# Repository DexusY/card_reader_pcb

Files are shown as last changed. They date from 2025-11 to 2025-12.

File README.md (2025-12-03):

# ESP32 RFID Access Control System

A compact and robust access control system based on the **ESP32-WROOM-32E** microcontroller and the **RFID-RC522** reader. This project allows for controlling an electric strike, electromagnetic lock, or gate upon presenting an authorized card.

The system is designed to run on **12V DC**, making it easy to integrate with standard alarm and intercom systems.

---

## PCB Visualization

The PCB design (2-layer) prioritizes power stability and RF signal integrity.

### Key PCB Features:
* **RF Optimization:** Dedicated "Keep-out zone" under the ESP32 antenna to ensure maximum WiFi/Bluetooth range.
* **Stable Power Delivery:** Wide power rails for the 3.3V line to prevent voltage drops during high current peaks.
* **Safety:** Physical isolation slots routed near the relay to increase creepage distance and safety.

PCB Traces view
PCB 3D View

---

## Schematic & Functional Description

The system is divided into three main functional blocks.

### 1. Power Supply Section
The input stage accepts **12V DC**. It utilizes a modern **LMR51610** (SOT-23-6) step-down converter to efficiently lower the voltage to the **3.3V** required by the ESP32 and RFID module.
* **Input:** 12V DC (Screw Terminal J1).
* **Filtering:** Ceramic capacitors and a 1.5uH inductor ensure a stable output.

Power Supply Schematic

### 2. MCU & User Interface
The core of the system is the **ESP32-WROOM-32E**. It handles the logic, wireless communication, and user feedback:
* **Feedback:** A Buzzer (BZ1) and 3 LEDs (Red, Yellow, Green) indicate access status.
* **Programming:** Exposed UART header (J3) with TX, RX, GND, 3.3V, IO0 (BOOT), and EN pins.

MCU Schematic
Goldpins connectors for programing and module

### 3. Actuator Output
The lock control mechanism is driven by a relay via an NPN transistor (Q1).
* **Output:** Screw Terminal J4 (NO - Normally Open contact).
* **Protection:** A flyback diode (D5) protects the transistor from voltage spikes generated by the relay coil.

Relay Schematic

---

##  Pinout & Connectors

| Designator | Type | Description |
| :--- | :--- | :--- |
| **J1** | Screw Terminal | **12V DC** Power Input |
| **J2** | Pin Header 1x8 | **RFID-RC522** Module Connector (SPI) |
| **J3** | Pin Header 1x5 | UART Programming Port (TX, RX, RST, BOOT, GND) |
| **J4** | Screw Terminal | Relay Output (Connect to Electric Strike) |

---

##  Bill of Materials (Key Components)

* **MCU:** ESP32-WROOM-32E (WiFi/BT Module)
* **Regulator:** LMR51610XF (DC-DC Step-Down)
* **Relay:** 12V Coil (Miniature SPST/SPDT)
* **Transistor:** NPN (e.g., BC817, SOT-23)
* **Inductor:** 1.5uH (Power inductor for the buck converter)
* **RFID:** RC522 Reader Module (connects to J2)

---

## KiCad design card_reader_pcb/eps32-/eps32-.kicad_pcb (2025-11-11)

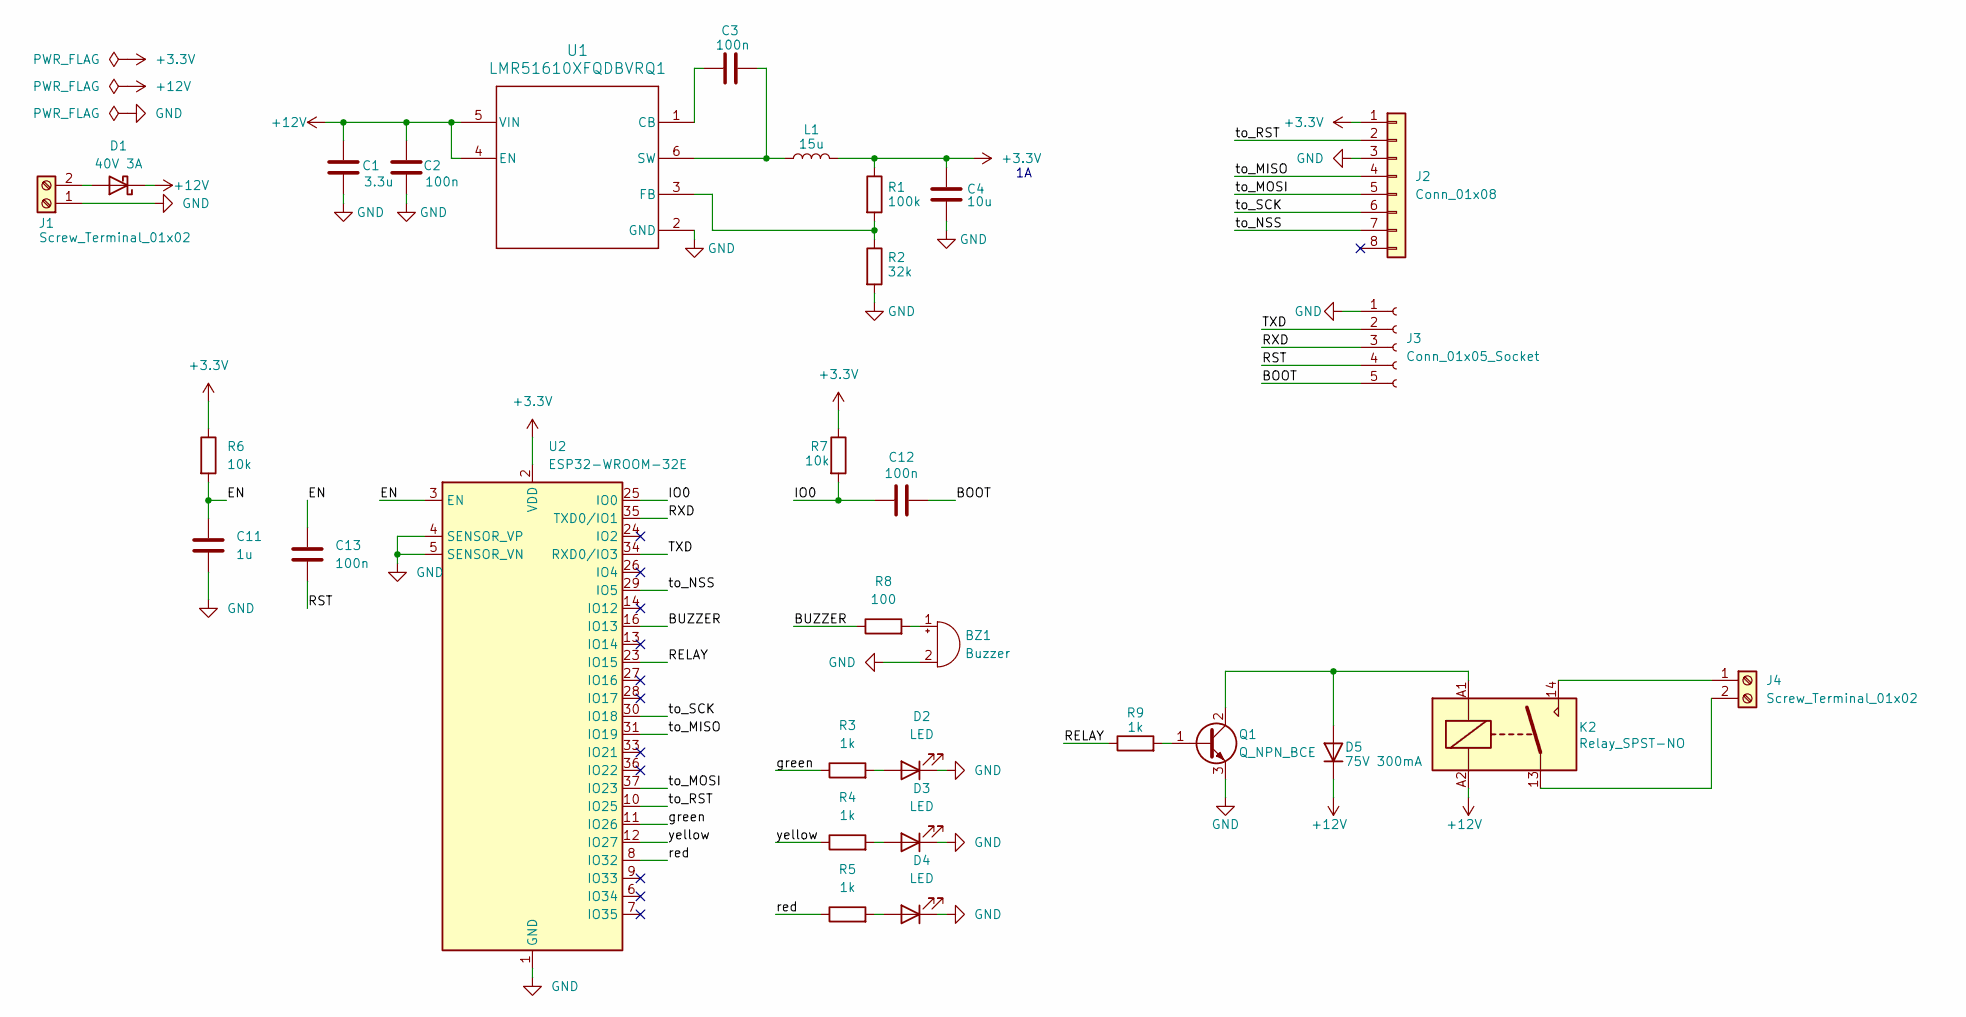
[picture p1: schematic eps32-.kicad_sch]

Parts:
BZ1: Buzzer; Buzzer_TDK_PS1240P02BT_D12.2mm_H6.5mm
C1: 3.3u; C_0201_0603Metric
C2, C3, C12, C13: 100n; C_0201_0603Metric
C4: 10u; C_0201_0603Metric
C11: 1u; C_0201_0603Metric
D1: 40V 3A; D_0402_1005Metric
D2, D3, D4: LED; LED_0201_0603Metric
D5: 75V 300mA; D_0201_0603Metric
J1, J4: Screw_Terminal_01x02; TerminalBlock_MaiXu_MX126-5.0-02P_1x02_P5.00mm
J2: Conn_01x08; PinSocket_1x08_P1.00mm_Vertical
J3: Conn_01x05_Socket; PinHeader_1x05_P1.00mm_Vertical
K2: Relay_SPST-NO; Relay_SPST_Finder_32.21-x300
L1: 15u; L_6.3x6.3_H3
Q1: Q_NPN_BCE; SOT-23
R1: 100k; R_0603_1608Metric
R2: 32k; R_0603_1608Metric
R3, R4, R5, R9: 1k; R_0603_1608Metric
R6, R7: 10k; R_0603_1608Metric
R8: 100; R_0603_1608Metric
U1: LMR51610XFQDBVRQ1; DBV0006A-IPC_C
U2: ESP32-WROOM-32E

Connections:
+3.3V: C4.1, J2.1, L1.2, R1.1, R6.1, R7.1, U2.2 (VDD)
+12V: C1.1, C2.1, D1.1 (K), D5.1 (K), K2.A2, U1.4 (EN), U1.5 (VIN)
/BOOT: C12.2, J3.5
/BUZZER: R8.1, U2.16 (IO13)
/EN: C11.1, C13.1, R6.2, U2.3 (EN)
/IO0: C12.1, R7.2, U2.25 (IO0)
/RELAY: R9.1, U2.23 (IO15)
/RST: C13.2, J3.4
/RXD: J3.3, U2.35 (TXD0/IO1)
/TXD: J3.2, U2.34 (RXD0/IO3)
/green: R3.1, U2.11 (IO26)
/red: R5.1, U2.8 (IO32)
/to_MISO: J2.4, U2.31 (IO19)
/to_MOSI: J2.5, U2.37 (IO23)
/to_NSS: J2.7, U2.29 (IO5)
/to_RST: J2.2, U2.10 (IO25)
/to_SCK: J2.6, U2.30 (IO18)
/yellow: R4.1, U2.12 (IO27)
GND: BZ1.2 (-), C1.2, C2.2, C4.2, C11.2, D2.1 (K), D3.1 (K), D4.1 (K), J1.1, J2.3, J3.1, Q1.3 (E), R2.2, U1.2 (GND), U2.1 (GND), U2.4 (SENSOR_VP), U2.5 (SENSOR_VN), U2.15 (GND), U2.38 (GND), U2.39 (GND)
unnamed: BZ1.1 (+), R8.2
unnamed: D1.2 (A), J1.2
unnamed: D2.2 (A), R3.2
unnamed: D3.2 (A), R4.2
unnamed: D4.2 (A), R5.2
unnamed: D5.2 (A), K2.A1, Q1.2 (C)
unnamed: J4.1, K2.14
unnamed: J4.2, K2.13
unnamed: Q1.1 (B), R9.2
unnamed: C3.1, U1.1 (CB)
unnamed: R1.2, R2.1, U1.3 (FB)
unnamed: C3.2, L1.1, U1.6 (SW)

Board: 2 copper layers, 31 parts (0 on the bottom side), 31 nets, no tracks yet.

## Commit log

2025-11-04 Enhance README with project details and components
    Added detailed project description and component list for ESP32 development board.
2025-12-03 Revise README for ESP32 RFID Access Control System
    Updated project description and added key features of the ESP32 RFID Access Control System. Enhanced PCB visualization and functional description sections.
